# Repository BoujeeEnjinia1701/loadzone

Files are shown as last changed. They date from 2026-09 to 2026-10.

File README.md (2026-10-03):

# LoadZone

     

**Area:** Smart Cities · **TRL:** 3 of 9 (proof of concept on paper) · **Value-engineering target:** USD 120 (estimated cost USD 116) · **Difficulty:** 2 of 5

A curbside loading bay occupancy sensor for streets that are not plowed: it shows delivery drivers which bays are free and gives cities data on curb use.

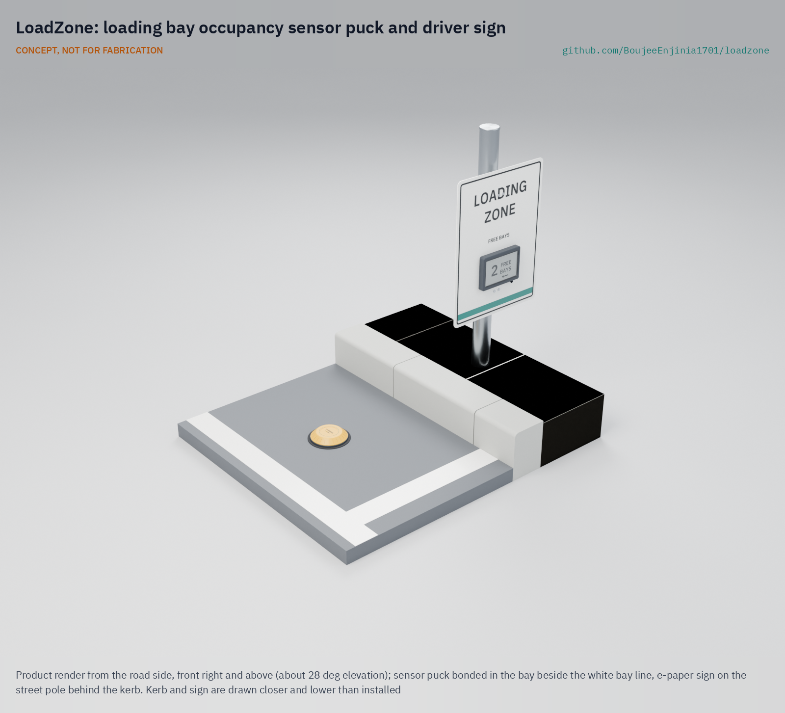
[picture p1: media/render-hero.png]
LoadZone: loading bay occupancy sensor puck and driver sign, product render


[Exploded render](media/render-exploded.png) · [Detail render](media/render-detail.png) · [Interactive 3D model](media/viewer.html) · [Concept blueprint (PDF)](media/concept-blueprint.pdf) · [General arrangement (PDF)](cad/drawings/LDZ-DWG-001.pdf) · [Sizing calculations](docs/04-calcs/01-sizing.md) · [Prototype build plan](docs/05-build-plan.md) · [Design decisions](docs/06-design-decisions.md) · [Review note](docs/REVIEW.md)

## Concept rationale

Knowing bay availability reduces circling and double parking. LoadZone puts a low, battery-powered puck in the middle of each vehicle slot of a loading bay. A magnetometer senses the steel body of a parked vehicle, and a LoRaWAN radio from the lab's FieldNode core reports "free" or "occupied" in about 18 s (39 s at worst). A server turns these reports into live bay state for drivers, and occupancy and dwell times for the city; a solar e-paper sign on an existing pole is an option.

It is open and garage-buildable because curb data should belong to the street, not to a vendor. A magnetometer cannot see faces or number plates, so privacy holds even if the firmware is changed, and anyone can inspect how a "free" or "occupied" call is made. The puck is a cast dome over potted off-the-shelf parts, bonded to the road like a raised pavement marker, and the data can be published in the open Curb Data Specification format so cities can compare it with carrier data.

## Burning platform

Loading bays are full, and often not with deliveries. In a study of downtown Seattle, passenger vehicles were 52 % of all vehicles parked in commercial load zones, and 41 % of commercial vehicles parked in unauthorized locations, rising to 55 to 65 % near retail centers ([Urban Freight Lab, 2019](https://urbanfreightlab.com/publications/the-final-50-feet-of-the-urban-goods-delivery-system-tracking-curb-use-in-seattle/)). The same group reports that commercial load zones often run at 90 % occupancy or more during business hours ([Urban Freight Lab](https://urbanfreightlab.com/final-50-feet/)). A driver who finds the bay taken stops in the traffic lane or the bike lane.

Pressure on the curb keeps rising. Online sales rose from 16 % to 19 % of all retail sales in 2020 ([UNCTAD, 2021](https://unctad.org/news/global-e-commerce-jumps-267-trillion-covid-19-boosts-online-sales)), and in Great Britain van traffic grew 2.3 % to 59.0 billion vehicle miles in the year to September 2024 ([Department for Transport](https://www.gov.uk/government/statistics/provisional-road-traffic-estimates-great-britain-october-2023-to-september-2024)). Cities cannot manage bays they cannot measure, and most loading bays today are measured only by occasional manual surveys.

## Where it could be used

### By industry

| Industry | Use |
| --- | --- |
| Municipal transport and curb management | Occupancy, turnover and dwell time by bay and hour, to size bays and set hours and pricing |
| Parcel, food and freight carriers | Route drivers to a free bay; fewer double-parked stops and tickets |
| Retail streets and business districts | Shared loading bays for shop suppliers, with evidence for more or better-placed bays |
| Parking enforcement | Find overstays in loading bays without patrols or cameras |
| Hospitals, campuses and industrial sites | Manage private loading bays and short-stay drop-off areas |
| Research and education | Open, reproducible curb-use data for transport studies |

### By country or region

| Country or region | Why it matters there |
| --- | --- |
| United States | In downtown Seattle, 41 % of commercial vehicles parked in unauthorized locations ([Urban Freight Lab, 2019](https://urbanfreightlab.com/publications/the-final-50-feet-of-the-urban-goods-delivery-system-tracking-curb-use-in-seattle/)); cities are now comparing curb programs through US DOT SMART grants ([Urban Freight Lab](https://urbanfreightlab.com/research-projects/open-mobility-foundation-smart-grant-curb-collaborative/)) |
| United Kingdom | Van traffic grew 2.3 % to 59.0 billion vehicle miles in the year to September 2024 ([Department for Transport](https://www.gov.uk/government/statistics/provisional-road-traffic-estimates-great-britain-october-2023-to-september-2024)) |
| European Union | Data protection by design is a legal duty ([Regulation (EU) 2016/679, Article 25](https://eur-lex.europa.eu/legal-content/EN/TXT/HTML/?uri=CELEX:32016R0679)), which favors curb sensors that cannot capture personal data at all |
| South Korea | Online sales reached 25.9 % of retail in 2020, the highest share UNCTAD reported ([UNCTAD, 2021](https://unctad.org/news/global-e-commerce-jumps-267-trillion-covid-19-boosts-online-sales)), so dense cities carry heavy parcel traffic |
| India | National guidelines for City Logistics Plans ask cities to optimize loading and unloading lots and to track the daily use of each bay and the number of deliveries it serves ([DPIIT, Guidelines for Preparing City Logistics Plan](https://www.dpiit.gov.in/static/uploads/2025/07/4e218c186c4bdbc202d9f1f62bb9b372.pdf)); a low-cost open sensor can supply that count without cameras |
| Brazil | São Paulo's traffic agency lists 1,749 on-street truck bays reserved for loading and unloading, paid by digital card for one or two hours ([CET São Paulo](https://www.cetsp.com.br/consultas/zona-azul/vagas-especiais/vagas-caminhao.aspx)); sensing could show drivers which are free and show the city how long each stop lasts |

## What sparked the idea

The starting point was San Francisco's SFpark pilot, which set magnetometer "pucks" into metered parking spaces to publish real-time availability. The agency's own sensor data guide records where that approach fell short: the in-ground sensors, 4 in (about 100 mm) across, had batteries intended to last about five years, cut to about three by noise-filtering software, yet some began to fail in late 2012 and early 2013, about a year earlier than expected, and users were advised to aggregate the data by hour and by block to reduce the effect of sensor error ([SFMTA, Parking Sensor Data Guide, 2013](https://www.sfmta.com/sites/default/files/reports-and-documents/2018/08/sfpark_dataguide_parkingsensordata.pdf)). LoadZone takes the same sensing principle to the loading bay, where stops last minutes rather than hours, and answers those lessons in the open: a surface-bonded puck that needs no coring, a cell budget derated 40 % against the five-year target, and firmware and data that a city can inspect rather than rent.

## Problem

Delivery vehicles double-park when loading bays are occupied or unknown, blocking lanes and bike paths. Drivers cannot see whether a bay is free before they reach it, and cities have no routine record of how their loading bays are used. See the [problem statement](docs/01-problem.md).

## Concept

A curbside loading bay occupancy sensor for streets that are not plowed: it shows delivery drivers which bays are free and gives cities data on curb use.

Full design precis: [docs/02-concept.md](docs/02-concept.md)

## Key components

- Surface-bonded bay sensor puck on a two-part road-marker epoxy bed, 150 mm diameter and 31 mm high, cast polyurethane over potted electronics, one per vehicle slot of about 7 m
- 3-axis magnetometer (LIS2MDL class) for vehicle detection
- FieldNode radio core (STM32WL-class LoRaWAN module) with an internal antenna
- Two AA-size lithium thionyl chloride cells, 7.7 years of life at SF9 (calculated, derated 40 %)
- Open server and data feed that maps onto the Curb Data Specification
- Solar signage option: 7.5 in e-paper sign on an existing pole, powered by a host FieldNode, legible by day; needs a private network server such as TwinKit

TRL 3 calculations ([LDZ-CAL-001](docs/04-calcs/01-sizing.md)): state reported in 17.7 s typically and 18.2 s at worst on US915, 7.7 years on one set of cells, and an estimated USD 116 in parts for a two-slot bay against a value-engineering target of USD 120 (USD 4 under it); the sign option (USD 101 plus a USD 139.50 FieldNode) is costed separately. No requirement is now not met. A puck under a parked van reaches a gateway about 340 m away in a street canyon, so each bay needs a gateway within 300 m (R4), and the e-paper sign is a daylight-only aid, unlit at night (R11). Detection of high-clearance trucks (R1), airtime at slow data rates (R5) and the epoxy road bond under braking (R6) are at risk. See the [design precis](docs/02-concept.md), [requirements](docs/03-requirements.md) and design decisions ([LDZ-DDR-001](docs/decisions/0001-trl2-review-decisions.md), [LDZ-DDR-002](docs/decisions/0002-recommendations-accepted.md), [LDZ-DDR-003](docs/decisions/0003-design-for-construction.md)). The parametric model is [cad/src/model.py](cad/src/model.py), with STEP files in `cad/step/`.

The working bill of materials is in [bom/bom.csv](bom/bom.csv).

## Building the prototype

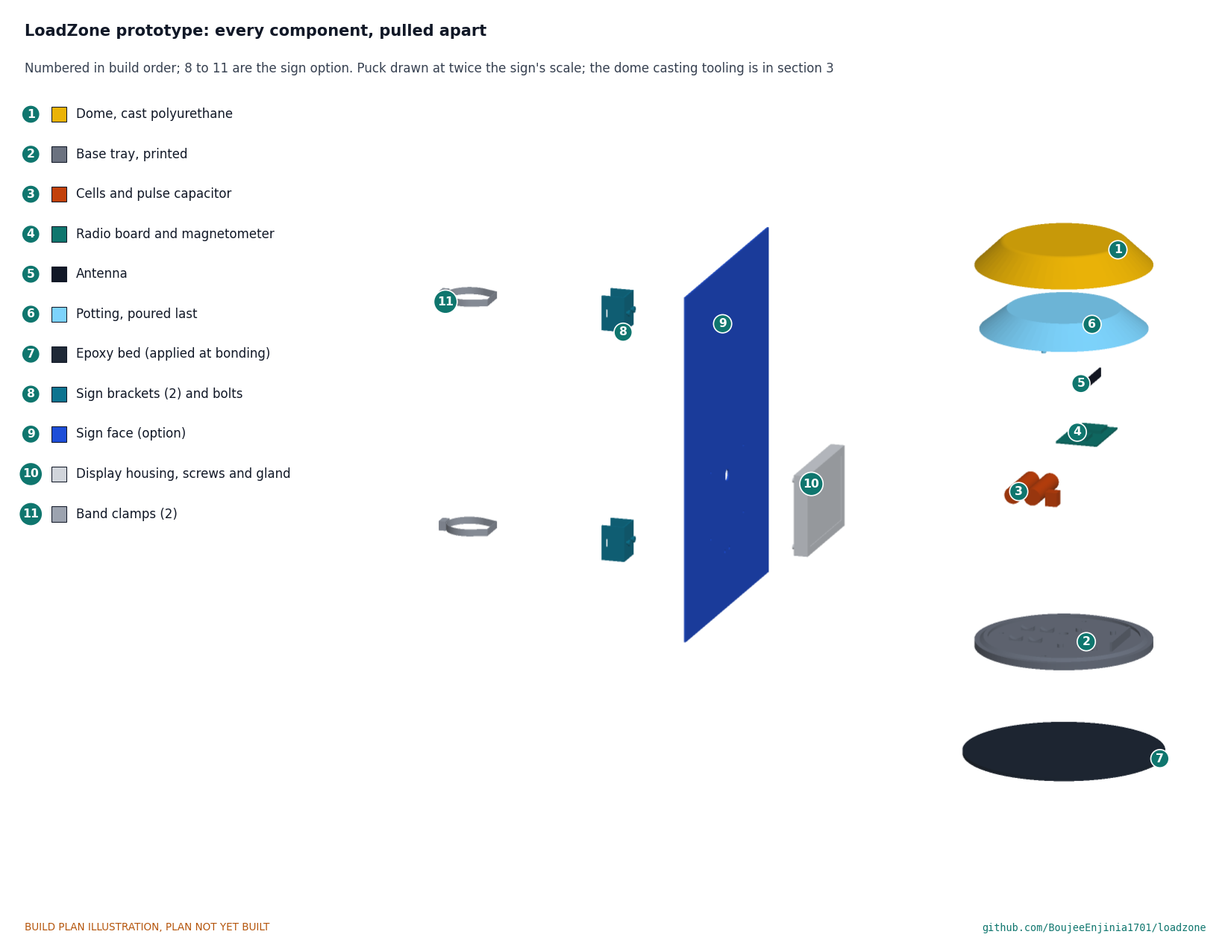
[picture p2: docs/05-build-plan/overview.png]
LoadZone prototype: every component pulled apart and numbered in build order


The [prototype build plan](docs/05-build-plan.md) (LDZ-BLD-001) shows, in pictures, how to make each of the eleven components and put them together in nine steps; nothing has been built yet. Each puck is a polyurethane dome cast in a home-made silicone mould with a printed core, on a printed base tray that holds the cells, radio board and antenna; the puck is then potted solid through a hole in the tray and bonded to a test slab. The sign option is a bought sign face and display housing on two aluminium channel brackets with band clamps. Writing the plan made the design buildable: the base became a tray with a locating ring, fill and vent holes and holders for every part, the dome got a real casting process, and the sign's solid ring clamps became brackets and bands (LDZ-DDR-003, accepted by Amish on 2026-10-02). Every picture is drawn from the model, which checks that each part touches what it should and clears what it should not.

## Safety

> Street furniture and pole mounts must be installed only with the asset owner's permission, by trained crews, with fall protection and traffic management as local rules require.
>
> Pucks are installed in the roadway: work only under a road permit and traffic management. The pucks contain primary lithium thionyl chloride cells: never recharge, short, crush or heat them. Road-marker adhesives and polyurethane casting resins are hazardous; follow their safety data sheets. The surface puck is not for plowed streets, and a sign's legend must follow the city's sign rules and be approved by its traffic engineer before it goes on a street.

## Repository layout

| Folder | Contents |
| --- | --- |
| `docs/` | Problem, concept, requirements, calculations, prototype build plan and design decisions |
| `cad/src/` | build123d Python source, the source of truth for all geometry |
| `cad/step/`, `cad/stl/` | Exported models for FreeCAD, other CAD tools and printing |
| `cad/drawings/` | 2D sketches and dimensioned drawings |
| `bom/` | Bill of materials |
| `electronics/` | KiCad schematics and PCB layouts |
| `firmware/` | Microcontroller code |
| `media/` | Renders, perspectives and photos |
| `build-log/` | Dated prototyping notes |

## Documentation

Controlled documents follow the portfolio [documentation standard](.kit/STANDARDS.md). Each carries a document ID (LDZ-PRC-001 for the precis), a version and a revision history. Branded PDFs are built with `python .kit/render.py` and attached to GitHub Releases when a document is tagged, for example `LDZ-PRC-001/v1.0`.

## Credits

Designed by Amish Chadha. See [CONTRIBUTORS.md](CONTRIBUTORS.md) for roles. To cite this design, use [CITATION.cff](CITATION.cff) (GitHub shows it as "Cite this repository").

AI assistance (Claude) was used to accelerate concept renders, prototype documentation and first-pass sizing calculations. Design direction and all decisions are Amish Chadha's, recorded in this repository's decision records (`docs/decisions/`).

## Licenses

- **Hardware** (CAD, drawings, BOM, electronics): [CERN-OHL-S v2](LICENSE)
- **Software** (firmware, scripts, notebooks): [MIT](LICENSE-SOFTWARE)

A project of the [Design Molecule](https://designmolecule.com) lab.

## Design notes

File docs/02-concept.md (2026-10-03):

---
doc_id: LDZ-PRC-001
title: LoadZone design precis
project: LoadZone
doc_type: Design precis
version: "0.7"
status: Draft
date: '2026-10-02'
author: Amish Chadha
license: CERN-OHL-S-2.0
revisions:
- version: "0.1"
  date: '2026-09-25'
  author: Amish Chadha
  change: Initial scaffold
- version: "0.2"
  date: '2026-09-25'
  author: Amish Chadha
  change: Populate to TRL 2 (architecture, components, first-order numbers, safety, open questions)
- version: "0.3"
  date: '2026-09-25'
  author: Amish Chadha
  change: TRL 3 figures from LDZ-CAL-001; design choices adopted for TRL 3 under LDZ-DDR-001; parametric model and drawing LDZ-DWG-001
- version: "0.4"
  date: '2026-09-25'
  author: Amish Chadha
  change: Recommendations accepted by Amish (DDR-002)
- version: "0.5"
  date: '2026-10-01'
  author: Amish Chadha
  change: "Constructable design (LDZ-DDR-003): base tray and sign brackets; cost against the value-engineering target"
- version: "0.6"
  date: '2026-10-02'
  author: Amish Chadha
  change: 'Decisions of 2026-10-02 carried in (LDZ-DEC-001 items 2 to 7): partner and US915, sealed for life, ASA tray, button heads, legend approval rule, surface puck only and not for plowed streets'
- version: "0.7"
  date: '2026-10-02'
  author: Amish Chadha
  change: 'Radio figures rerun for US915 with the 11-byte payload (LDZ-CAL-001 v0.4): airtime, latency, cell life, link; antenna at 915 MHz; no requirement status changed'
---

# LoadZone design precis

## Summary

LoadZone is a low, battery-powered puck bonded to the road in the middle of each vehicle slot of a loading bay. A 3-axis magnetometer senses the change in the Earth's magnetic field when a vehicle's steel body parks over it, and a LoRaWAN radio from the lab's FieldNode core reports "free" or "occupied" in about 18 s (39 s at worst at SF9). A server turns the reports into bay state, dwell times and an open data feed that maps onto the Curb Data Specification, and, as an option, a solar e-paper sign on an existing pole shows approaching drivers how many slots are free. The TRL 3 calculations (LDZ-CAL-001) give a cell life of 7.7 years at SF9 on two AA-size lithium thionyl chloride cells and a two-slot bay kit estimated at USD 116 in parts against a value-engineering target of USD 120. They also find the weak points: from road level under a parked van a puck reaches a gateway only about 350 m away in a street canyon, so each bay needs a gateway within 300 m (R4 as restated); the road bond is at risk under braking; and the sign is unlit, so it serves drivers by day only (R11 as restated). The design choices below were decided by Amish on 2026-09-25 (LDZ-DDR-001 and LDZ-DDR-002). Writing the prototype build plan (LDZ-BLD-001) made the design constructable without changing what it does (LDZ-DDR-003, open for Amish's review); open items are in the design decisions register (LDZ-DEC-001).

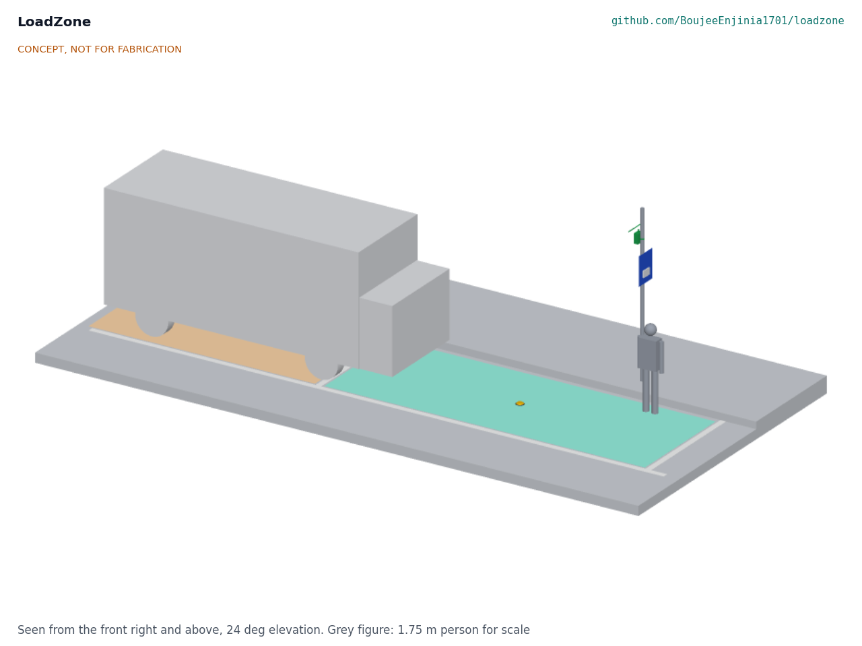
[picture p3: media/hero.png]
LoadZone concept


Figure 1. Concept massing model in a two-slot loading bay: the free slot (teal) with its puck, the occupied slot (orange) under a van, and the optional sign on an existing pole, with a 1.75 m person for scale. CONCEPT, NOT FOR FABRICATION.

## How it works

1. **Sense.** Each puck wakes about once a second and takes a single magnetometer reading. With no vehicle, the reading is the local Earth field plus a fixed offset learned at install. A car or van parked above distorts the field by several microtesla (estimate), mostly in the vertical axis.
2. **Decide.** Firmware compares the field change with an adaptive threshold and requires the new state to hold for about 15 s before accepting it, so traffic passing in the next lane and vehicles pausing briefly do not count. The baseline is re-learned slowly while the slot is free, to follow temperature drift and road works nearby.
3. **Report.** On each confirmed change, and hourly as a heartbeat, the puck sends an 11-byte LoRaWAN uplink: slot state, time since the last change, a confidence value, cell voltage and temperature. The payload is packed to 11 bytes so that it fits the slowest US915 rate (LDZ-DDR-002), and US915 is the default band. No raw magnetic data leave the device by default.
4. **Aggregate.** A LoRaWAN network server (TwinKit, The Things Network or a city network) passes uplinks to a small open service that keeps bay state, computes occupancy and dwell time, and publishes them in a form that maps onto the Curb Data Specification Events and Metrics APIs ([Open Mobility Foundation](https://www.openmobilityfoundation.org/about-cds/)).
5. **Show (option).** A FieldNode on a nearby pole, running as a LoRaWAN class C device, receives a short downlink when the bay state changes and redraws a 7.5 in e-paper panel set into a "Loading zone" sign: the number of free slots and an arrow. The same state can appear in carriers' routing tools and city maps through the data feed.

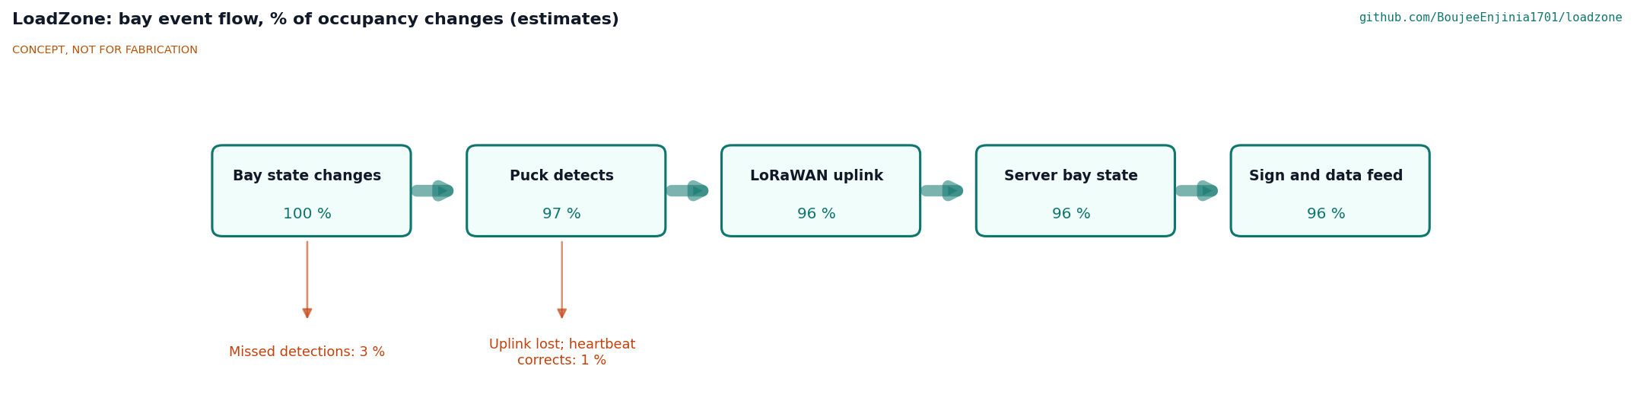
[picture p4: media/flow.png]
Event flow


Figure 2. Bay event flow, in percent of real occupancy changes (estimates, to be measured in a field trial).

## Main components

Table 1. Components (numbers match `bom/bom.csv` and Figure 3)

| No. | Component | Concept choice |
| --- | --- | --- |
| 1 | Puck dome | Rigid cast polyurethane, high-visibility yellow, 150 mm base diameter, 104 mm crown with a 6 mm radius, 31 mm total height, radio-transparent |
| 2 | Magnetometer | 3-axis, 16-bit, LIS2MDL class, on a small breakout ([STMicroelectronics](https://www.st.com/en/mems-and-sensors/lis2mdl.html)) |
| 3 | Controller and radio | STM32WL-class LoRaWAN module on a small carrier, the same core as FieldNode |
| 4 | Antenna | Flexible PCB antenna for 915 MHz (US915 default band), fixed inside the dome wall, above the cells |
| 5 | Cells | Two AA-size Li-SOCl2 bobbin cells (about 2.6 Ah each, typical rating) in parallel through one Schottky diode each, with an 85 °C hybrid pulse capacitor to supply transmit current |
| 6 | Base and potting | Printed 150 x 6 mm base tray with a ring that locates the dome, cradles for the cells, standoffs for the board and a rib for the antenna; the dome cavity is fully potted in semi-rigid polyurethane through a fill hole in the tray, and the potting carries wheel loads through to the base (LDZ-DDR-003) |
| 7 | Road-marker epoxy bed | Two-part road-marker epoxy, as used for raised pavement markers, as a 170 mm bed about 3 mm thick (LDZ-DDR-002; a bitumen pad is no longer used) |
| 8 | Sign face (option) | Aluminium composite panel, 450 x 600 mm, "Loading zone" legend and a window for the display |
| 9 | Display (option) | 7.5 in e-paper panel with driver board, behind a polycarbonate window in a sealed housing |
| 10 | Sign brackets (option) | Two aluminium channel brackets bolted to the back of the sign, each with a stainless band clamp for 60 to 90 mm poles (LDZ-DDR-003) |
| 11 | Host FieldNode (option) | Standard FieldNode (6 W panel, LiFePO4 cell, LoRaWAN class C), mounted above the sign and priced once in the FieldNode repo ($126.00) |

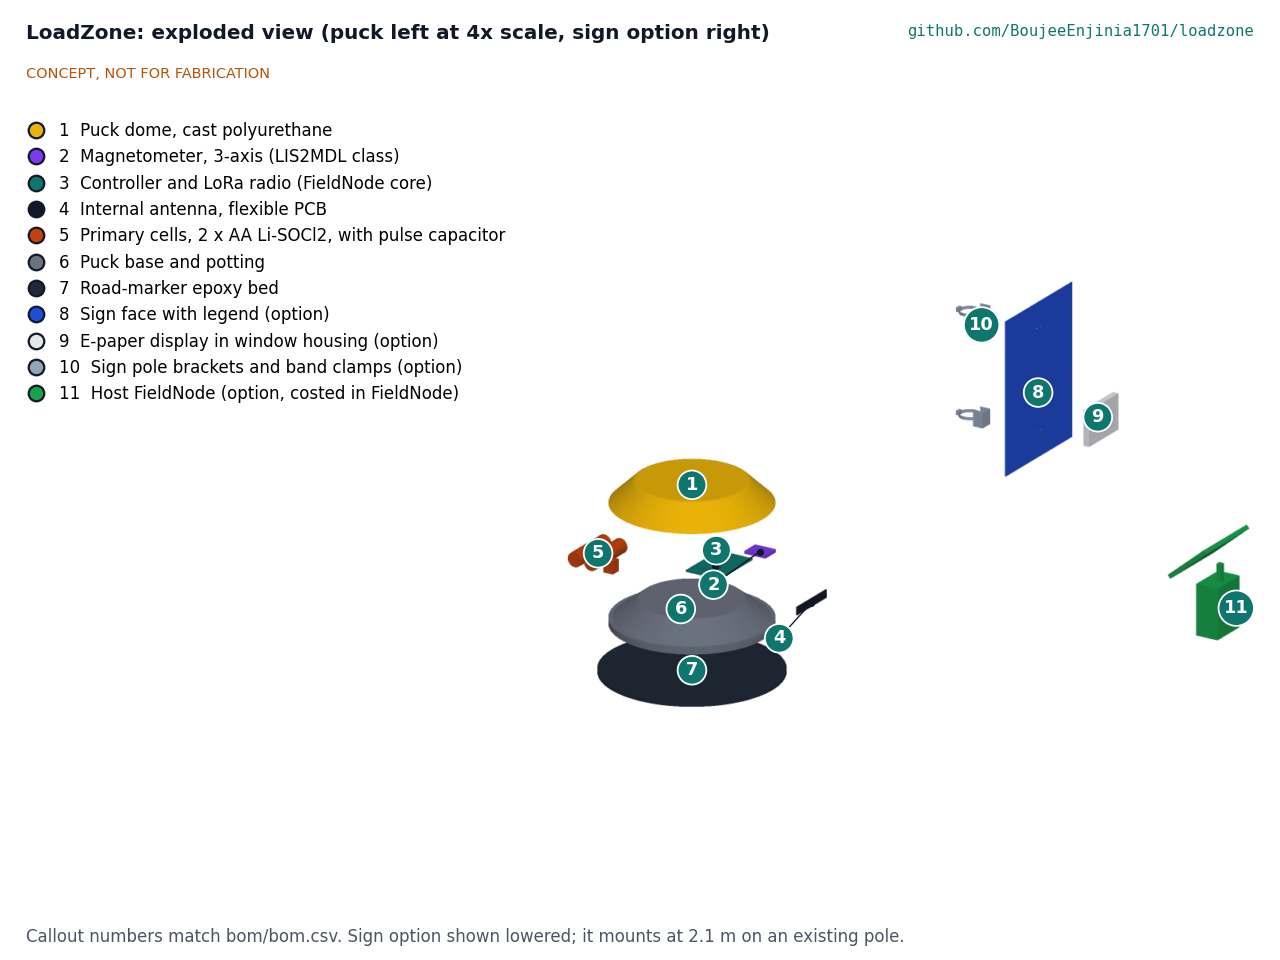
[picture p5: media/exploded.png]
Exploded view


Figure 3. Exploded view; callout numbers match `bom/bom.csv`. The puck is drawn at 4x scale.

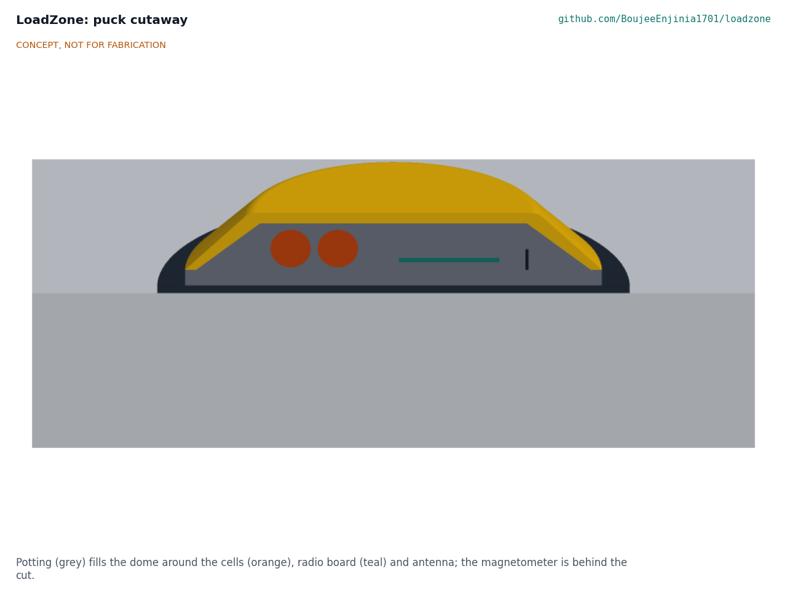
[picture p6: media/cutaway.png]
Cutaway


Figure 4. Puck cutaway: potting (grey) fills the dome around the cells (orange), the radio board (teal) and the antenna at the dome's edge; the magnetometer sits on the board behind the section plane.

The parametric model is `cad/src/model.py` (STEP and STL in `cad/step/` and `cad/stl/`), and the general arrangement of the puck is drawing LDZ-DWG-001 at Rev P2 in `cad/drawings/`.

## First-order numbers

All values are from LDZ-CAL-001 v0.2, which the script `docs/04-calcs/sizing.py` reproduces. They are paper estimates, not measurements.

Table 2. Puck energy budget at SF9

| Quantity | Value | Assumption |
| --- | --- | --- |
| Sleep | 0.144 mAh/day | 6 µA: module in stop mode, magnetometer idle, leakage |
| Sampling | 0.480 mAh/day | One reading a second; 10 ms awake at 2 mA (20 µA average) |
| Uplinks | 0.488 mAh/day | 100 state changes and 24 heartbeats, 14.2 mA·s each at SF9 |
| Total | 1.11 mAh/day, 0.406 Ah/year | Sum of the above |
| Usable cell capacity | 3.12 Ah | 2 x 2.6 Ah, derated 40 % for cold, pulse loads and self-discharge |
| Cell life | 7.7 years | 9.6 years at SF7, 6.2 at SF10; R3 asks for 5 years |

**Airtime.** An 11-byte uplink is on air for 61.7 ms at SF7, 205.8 ms at SF9 and 370.7 ms at SF10, inside the 400 ms US915 dwell limit. At 124 uplinks a day that is 7.7 s at SF7 and 25.5 s at SF9, within The Things Network's 30 s fair-use limit ([TTN](https://www.thethingsnetwork.org/docs/lorawan/duty-cycle/)), but 46.0 s at SF10 (SF11 and SF12 are not offered on US915 uplinks). Pucks must therefore sit within SF9 reach of a gateway (R5 at risk).

**Latency.** A 15 s debounce, up to 1 s of sampling and about 2 s of network path give 17.7 s typically; US915 has no duty-cycle wait, so the worst case is 18.2 s at SF9 and 18.4 s at SF10, well within R2's 60 s.

**Pulse supply.** One SF9 uplink draws 9.3 mC, which a capacitor alone would supply with 0.3 V of droop at 31 mF (56 mF at SF10). Fresh cells sit at about 3.67 V, above the module's 3.6 V limit, so one Schottky diode per cell drops the rail to about 3.42 V and stops one cell charging the other.

**Detection.** The Earth's field is roughly 25 to 65 µT, well within the sensor's ±50 gauss (±5,000 µT) range. A line-dipole model calibrated to an assumed 10 µT under a parked van gives 10.6 µT for a car, 7.7 µT for a high-chassis box truck and 3.85 µT for a truck with little low steel, against a 3 µT threshold, while a van in the next lane gives 0.46 µT. The slot-center position sees vehicles anywhere in the slot and ignores neighbors; high-clearance trucks are the weak case, and R1 stays unverified until field data exist.

**Link.** At 11.5 dBm EIRP the SF9 link budget is 141.0 dB. With 10 dB lost at road level and 10 dB to a van overhead, the 3GPP urban microcell street-canyon model at 915 MHz leaves -6.4 dB at 1 km out of sight and 2.6 dB in line of sight; the range out of sight is about 340 m with a 10 dB fade margin. The original 1 km target is not reachable, so R4 is restated as a gateway within 300 m of each bay (LDZ-DDR-002), which the 342 m range meets on paper.

**Load.** A 49 kN wheel (half of a 10 t axle) on the 92 mm flat crown gives 7.38 MPa, or 9.59 MPa with a 1.3 dynamic factor: a factor of 5.4 on rigid cast polyurethane and 2.0 on the potting beneath. The bond is the weak point: a braking tire could push 34.3 kN sideways, 1.51 MPa on the bed, against about 1.0 MPa for two-part epoxy on asphalt at 20 °C and much less when hot. A vehicle parked inside the bay lines keeps its tires at least 275 mm from the puck axis, so only maneuvering wheels cross it; R6 is restated on that basis with an epoxy bed (LDZ-DDR-002) and stays at risk.

**Sign.** Class C listening costs 15.2 mW and about 200 e-paper redraws a day add 0.015 Wh; the sign draws 0.42 Wh a day (17.7 mW), well within FieldNode's published allowance of 100 mW. Digits 78 mm high read at about 28 m by day on the MUTCD legibility index, better than the 10 m estimated at TRL 2, but the panel is unlit, and a 0.5 W front light would need 6.0 Wh a day, 2.5 times the allowance, so R11 is restated as a daylight-only target (LDZ-DDR-002) and met on paper. The sign takes about 200 downlinks a day, far above The Things Network's 10, so it needs a private network server such as TwinKit (decided, LDZ-DDR-002). Typical 7.5 in e-paper panels operate from about 0 to 50 °C, so refresh on freezing days is a limit to check.

**Mass and size.** Puck 451 g without the pad (75 g), 150 mm diameter, 31 mm high.

**Cost.** Value-engineering target: USD 120, for the two-puck kit only (LDZ-DDR-001, D6). Estimated cost of the constructable design: USD 116 (USD 4 under the target). The sign option adds USD 101 plus a host FieldNode at USD 126, and the one-off dome casting tooling USD 35 (see `bom/bom.csv`).

## Key design choices

Choices 1 to 7 and 9 to 11 are decided by Amish, 2026-09-25: go with recommendation (LDZ-DDR-001, D1 to D8, and LDZ-DDR-002). Choice 8 follows from choice 2. Choices 12 and 13, and the scope note in choice 1, were decided by Amish on 2026-10-02 (LDZ-DEC-001).

1. **Surface-bonded puck rather than an in-ground (cored) sensor.** No road works for a pilot and easy removal. In-ground units are better protected from plows and theft. Decided by Amish, 2026-10-02 (LDZ-DEC-001, item 7): only the surface puck is offered for now, and it is not for plowed streets; the cored, in-ground version is recorded as a later option.
2. **Magnetometer only, rather than magnetometer plus radar.** Lowest cost and power. A small radar looking up through the dome could confirm detections; it stays an open option if R1 is not met in trials.
3. **One puck per vehicle slot of about 7 m**, rather than one per bay. Bays hold one to three vans; slot-level state lets the sign say "1 free" rather than "space somewhere".
4. **Primary Li-SOCl2 cells rather than rechargeable cells with a solar cell on the puck.** A road-level solar cell is shaded by parked vehicles and soiled by tires. Two AA cells give margin over the 5-year target.
5. **LoRaWAN with the FieldNode core.** Shared firmware, tools and gateways across the lab. The sign, as a class C device, receives state by downlink (D7). At about 200 downlinks a day this needs a private network server such as TwinKit; on The Things Network the sign would have to listen to the pucks directly (LoRa point to point), which also keeps it working when the internet link is down. The sign option therefore requires a private network server or a city network that allows the downlinks (LDZ-DDR-002, O5).
6. **E-paper sign as an option, not the core.** It needs no power to hold an image and is readable in sun, but it is small and unlit, so its target is daylight only (R11) and drivers use the data feed at night. Many drivers may use the data through routing tools instead, which co-design should test.
7. **Open data in a Curb Data Specification form**, so a city can compare LoadZone with carrier and payment data.
8. **Privacy by physics.** The puck senses only a magnetic field, so it cannot identify vehicles or people even if its firmware is changed.
9. **Two-part road-marker epoxy bed** rather than a bitumen pad, for bond strength, with R6 restated around maneuvering wheels (LDZ-DDR-002, O3). Pull-off testing is TRL 4 work and on hold.
10. **A gateway within 300 m of each bay** (R4 restated, LDZ-DDR-002, O2), which also keeps pucks at SF9 or faster for R2, R3 and R5.
11. **Supply and potting details:** one Schottky diode per cell, an 85 °C hybrid pulse capacitor, a fully potted cavity and a 6 mm crown radius (LDZ-DDR-002, O6), and an 11-byte payload (O7).
12. **Sealed for life** (LDZ-DEC-001, item 3, decided 2026-10-02): the cells cannot be replaced and the firmware changes only over the air; over-the-air updates are planned for TRL 4. The base tray is printed ASA sanded with 80 grit (item 4), and the sign face shows button heads (item 5).
13. **US915 as the default band** (LDZ-DEC-001, item 2, decided 2026-10-02), since the 11-byte payload already fits it.

## Relationship to other lab projects

- **FieldNode** provides the controller and radio core (the STM32WL-class module) for the puck and the complete host node for the sign option, as its README lists LoadZone among adopting projects. LoadZone uses FieldNode's radio currents and its $126.00 core cost (FND-CAL-001); the sign's 17.7 mW fits FieldNode's published 100 mW allowance.
- **TwinKit** is the default gateway and data platform, and the sign option needs it (or another private network server) for its class C downlinks; for the pucks alone, any LoRaWAN network server works.
- **CurbCount** counts people, bicycles and vehicles passing the curb; LoadZone reports who is stopped at it. Both would feed **CityTwin**.
- **CalRig** could check magnetometer offset and noise before installation.

## Safety

> **Safety:** Installing on a road is dangerous. Work only with the road authority's permit, with a trained crew, under the traffic management that local rules require, and with high-visibility clothing. Never install from a live traffic lane without protection.

> **Safety:** Lithium thionyl chloride cells are primary lithium cells. Do not recharge, short, crush, heat or open them; they can vent toxic and corrosive gas and burn. Connect the two cells in parallel only through one diode each so that one cell can never charge the other, fit a fuse, keep the pulse capacitor within its voltage and temperature rating, and recycle spent cells as hazardous waste.

> **Safety:** Two-part road-marker epoxy is chemically hazardous and some grades are applied hot; uncured resin and hardener irritate skin and can sensitize. Follow the maker's safety data sheet, wear gloves and eye protection, and ventilate. Polyurethane casting resins contain isocyanates; cast only with ventilation and suitable respiratory protection.

> **Safety:** The puck is a raised object in the roadway. Keep it low with rounded edges, place it away from bike lanes and crosswalks, and keep it high-visibility. Check after install that it is fully bonded, since a loose puck can be thrown by a tire.

> **Safety:** The sign option is work at height on a street pole. Use a stable platform with a second person present, keep clear of overhead power lines, and use only poles whose owner permits the added wind load. Deburr the aluminium sign panel's edges. The prototype legend is a placeholder: before a sign is mounted on a street, its legend is drawn to the trial city's sign rules (in the US, the MUTCD) and approved by the city traffic engineer (LDZ-DEC-001, item 6).

## Open questions

- [ ] Detection accuracy with magnetometer only, especially for high-clearance trucks: is a radar or second magnetometer needed to meet R1? Awaiting field data.
- [x] Gateway spacing: a gateway within 300 m of each bay (R4 restated, LDZ-DDR-002).
- [x] Bond: two-part road-marker epoxy, with R6 restated (LDZ-DDR-002).
- [x] Sign: daylight-only target, on a private network server (LDZ-DDR-002).
- [x] First trial partner and band (O1). Decided by Amish, 2026-10-02 (LDZ-DEC-001, item 2): the first candidate type to approach, not yet agreed, is a city curb-management or transportation team that has published or piloted the Curb Data Specification, in a city without routine snow plowing; US915 by default, with the 11-byte payload.
- [x] Snow and plows. Decided by Amish, 2026-10-02 (LDZ-DEC-001, item 7): the surface puck is not for plowed streets; a cored, in-ground version is a later option.

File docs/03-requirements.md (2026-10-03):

---
doc_id: LDZ-REQ-001
title: LoadZone requirements
project: LoadZone
doc_type: Requirements
version: "0.7"
status: Draft
date: '2026-10-02'
author: Amish Chadha
license: CERN-OHL-S-2.0
revisions:
- version: "0.1"
  date: '2026-09-25'
  author: Amish Chadha
  change: Initial scaffold
- version: "0.2"
  date: '2026-09-25'
  author: Amish Chadha
  change: First measurable requirements for TRL 2, with status against the concept
- version: "0.3"
  date: '2026-09-25'
  author: Amish Chadha
  change: TRL 3 status from LDZ-CAL-001; R6 load basis set; R13 redefined to the two-puck kit (LDZ-DDR-001 D6)
- version: "0.4"
  date: '2026-09-25'
  author: Amish Chadha
  change: Recommendations accepted by Amish (DDR-002)
- version: "0.5"
  date: '2026-10-01'
  author: Amish Chadha
  change: Constructable design (LDZ-DDR-003); R13 reported against the value-engineering target
- version: "0.6"
  date: '2026-10-02'
  author: Amish Chadha
  change: 'Band assumption: US915 by default (LDZ-DEC-001, item 2, decided 2026-10-02); no status changed'
- version: "0.7"
  date: '2026-10-02'
  author: Amish Chadha
  change: 'Calculation figures brought into line with LDZ-CAL-001 v0.4 (US915); no requirement status changed'
---

# LoadZone requirements

These are the requirements for the concept, checked by calculation at TRL 3 in LDZ-CAL-001 v0.4 on the constructable design of LDZ-DDR-003 and the US915 default band (LDZ-DEC-001, item 2); neither changes a requirement status. On 2026-09-25 Amish accepted the recommendations (LDZ-DDR-002), so this version restates three targets: R4 is now a gateway within 300 m of the bay rather than 1 km; R6 is restated with the finding that the wheels of a vehicle parked inside the bay lines straddle the puck, and the bond is two-part road-marker epoxy; and R11 is a daylight-only target. R13 covers the two-puck bay kit only, with the sign option costed separately (LDZ-DDR-001 D6, now decided); its figure is a value-engineering target, not a spending limit (Amish, 2026-10-01). R12 uses FieldNode's published 100 mW allowance.

Table 1. Requirements

| ID | Requirement | Target | Status at TRL 3 (LDZ-CAL-001) | Verification |
| --- | --- | --- | --- | --- |
| R1 | Detect the state of each vehicle slot | 97 % or more of slot states correct over a day, for cars, vans and box trucks, with traffic passing in the next lane | **At risk**, not verifiable at TRL 3: a line-dipole model puts a van at 10.0 µT, a weak-steel box truck at 3.85 µT and next-lane traffic at 0.46 µT against a 3 µT threshold, on an assumed calibration | Field trial against a manual count or time-lapse survey (TRL 5) |
| R2 | Report changes quickly | Slot state at the server within 60 s of a vehicle arriving or leaving | Met on paper: 17.7 s typical, 18.2 s worst at SF9, 18.4 s at SF10 (US915 has no duty-cycle wait) | Timing calculation (TRL 3) |
| R3 | Long battery life | 5 years or more at 100 state changes a day plus hourly heartbeats | Met on paper: 7.7 years at SF9 on two AA-size Li-SOCl2 cells derated 40 %; 6.2 years at SF10 | Power budget calculation (TRL 3) |
| R4 | Reach a gateway from road level | Uplinks received by a gateway within 300 m of the bay in a street canyon, with a van parked over the puck (restated from 1 km, LDZ-DDR-002) | Met on paper: 342 m out of sight at SF9 with a 10 dB fade margin, 1.14 times the distance | Link budget (TRL 3), then field survey |
| R5 | Stay within network fair use | 30 s or less of uplink airtime per puck per day ([TTN fair use](https://www.thethingsnetwork.org/docs/lorawan/duty-cycle/)) | **At risk**: 25.5 s a day at SF9, but 46.0 s at SF10 (SF11 and SF12 are not offered on US915 uplinks) | Airtime calculation (TRL 3) |
| R6 | Survive traffic | Withstand a maneuvering wheel crossing the puck at 49 kN (half of a 10 t single axle), 64 kN with a 1.3 dynamic factor, and repeated drive-overs by loaded trucks, without cracking or debonding, on a two-part road-marker epoxy bed. The puck sits at the slot center so that the wheels of a vehicle parked inside the bay lines straddle it (restated, LDZ-DDR-002) | **At risk**: crushing met on paper (factor 5.4 on the cast dome, 2.0 on the potting); parked wheels clear the puck by at least 275 mm; bond shear under braking 1.51 MPa against about 1.0 MPa assumed for epoxy on asphalt | Load calculation (TRL 3), then load and pull-off test (TRL 4, on hold) |
| R7 | Safe, low profile | Height 35 mm or less above the road, rounded edges, high-visibility color | Met on paper: 31 mm high, 150 mm diameter, 6 mm crown radius, yellow dome | Parametric model and drawing LDZ-DWG-001 |
| R8 | Weather and temperature | Sealed to IP68; operate from -25 to +70 °C road surface temperature; resist salt, oil and fuel | Met by design: parts rated -40 to +85 °C with an 85 °C pulse capacitor; fully potted. Sealing not verifiable at TRL 3 | Datasheet review (TRL 3), then immersion test |
| R9 | Privacy by design | Only slot state, timestamps and device health leave the device; no images, audio or vehicle identifiers | Met by design: a magnetometer cannot read plates or faces | Design review |
| R10 | Open data | Bay state available through an open API that maps onto the Curb Data Specification Events and Metrics APIs ([Open Mobility Foundation](https://www.openmobilityfoundation.org/about-cds/)) | Met by design: events map onto `park_start`, `park_end`, `scheduled_report`, `comms_lost` and `comms_restored` | Design review (TRL 3) |
| R11 | Sign legible to drivers (option) | Free-slot count legible at 25 m by day (daylight only, restated, LDZ-DDR-002); at night drivers use the data feed | Met on paper: about 28 m by day at full contrast with 78 mm digits | Legibility calculation (TRL 3) |
| R12 | Sign power (option) | Sign runs within the host FieldNode's sensor energy allowance | Met on paper: 0.42 Wh a day (17.7 mW) against FieldNode's published 100 mW; needs a private network for its 200 downlinks a day (LDZ-DDR-002, O5) | Power budget (TRL 3) |
| R13 | Low cost | Two-puck bay kit in parts at quantity 1 against a value-engineering target of USD 120; the sign option and its host FieldNode are costed separately and excluded | Met on paper: estimated USD 116.00, USD 4.00 under the target. Sign option USD 101.00 plus a FieldNode at USD 126.00 | Priced BOM |
| R14 | Quick install without road works | One puck bonded in 15 min or less by a two-person crew; removable without damaging the road | Not verifiable at TRL 3 | Install trial (TRL 4 or later) |
| R15 | Tamper and theft resistant | No external screws; removal needs a heat gun or scraper; device reports removal | Met by design: bonded, no fasteners; removal flagged by a sudden field and orientation change | Design review (TRL 3) |

## Requirements at risk at TRL 3

No requirement is now not met. Before LDZ-DDR-002, R4 (1 km) and R11 (night) were not met; both are restated and met on paper.

- **R1 (detection)** is at risk for high-clearance trucks and rests on an assumed signal; only field data can settle it.
- **R5 (airtime)** is not met at SF10, the slowest US915 rate; R2 and R3 still hold there, but pucks must be placed within SF9 reach of a gateway, which the 300 m gateway distance in R4 supports.
- **R6 (traffic)** is at risk on debonding under braking, even with the epoxy bed; a pull-off and shear test on asphalt would settle it, but that is TRL 4 work and on hold.

## Assumptions

- A vehicle slot is about 7 m long and the puck sits near its center, 1.3 m from the curb face (estimates; bay layouts vary by city).
- Loading bay turnover of up to 50 vehicles a slot a day, or 100 state changes, based on most delivery stops lasting 30 minutes or less ([Urban Freight Lab, 2019](https://urbanfreightlab.com/publications/the-final-50-feet-of-the-urban-goods-delivery-system-tracking-curb-use-in-seattle/)).
- Each 11-byte LoRaWAN uplink costs about 14.2 mA·s at SF9 with FieldNode's radio currents (LDZ-CAL-001). US915 is the default band (LDZ-DEC-001, item 2, decided 2026-10-02), so the payload is packed to 11 bytes (LDZ-DDR-002) and LDZ-CAL-001 v0.4 uses the US915 rules (no duty cycle, 400 ms dwell limit, SF7 to SF10 on uplinks).
- The wheel load is half of a 10 t single axle (49 kN); a vehicle parked inside the bay lines straddles the puck, so wheel loads come from maneuvering (LDZ-CAL-001, section 7).

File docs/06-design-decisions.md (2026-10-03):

---
doc_id: LDZ-DEC-001
title: LoadZone design decisions register
project: LoadZone
doc_type: Design decisions register
version: "0.3"
status: Draft
date: '2026-10-02'
author: Amish Chadha
license: CERN-OHL-S-2.0
revisions:
  - version: "0.1"
    date: '2026-10-01'
    author: Amish Chadha
    change: Register opened with the open decisions from the review note, the decision records and the build plan work; budget treated as a value-engineering target
  - version: "0.2"
    date: '2026-10-02'
    author: Amish Chadha
    change: Amish approved the recommendations of open items 1 to 10 on 2026-10-02; all moved to decisions made; tray bond line to confirm updated
  - version: "0.3"
    date: '2026-10-02'
    author: Amish Chadha
    change: 'Value engineering: host FieldNode priced at USD 139.50 (FND-CAL-001)'
---

# LoadZone design decisions register

Every design decision still to be made, and every decision made, in one place. Each decision is argued in full in its decision record under `docs/decisions/`; this register is the index Amish works from. The build plan (`docs/05-build-plan.md`) describes the design as it stands and does not list open decisions.

## Open decisions

None. All open decisions were decided on 2026-10-02.

## To confirm when parts are bought

| # | What to confirm | Why it matters | Source |
| --- | --- | --- | --- |
| 1 | The display enclosure's real size, its clear lid and its wall thickness | The 4 screw holes, the gland hole and the sign face holes are drawn for about 200 x 140 x 24 mm; move them to suit | LDZ-DDR-003, P8 |
| 2 | The e-paper driver board takes commands from the host FieldNode over a cable about 1 m long, and the pin assignment of the FieldNode sensor port | Sets the cable and connector between the sign and the FieldNode; the FieldNode port pinout is still open in FieldNode | LDZ-DDR-003, P8; FND-DEC-001 |
| 3 | The band clamp range covers the band path for 60 to 90 mm poles (about 250 to 330 mm) | The band runs through the bracket as well as round the pole | LDZ-DDR-003, P7 |
| 4 | The silicone cures against the primer used on the master and core | Some primers stop platinum silicone curing | Build plan, section 3.2 |
| 5 | The potting's peak exotherm for about 175 cm³ against the cells' temperature rating | The potting is poured over live cells | Build plan, safety stop S4 |
| 6 | The magnetic offset of the cells' steel cans at the magnetometer, about 30 mm away | A fixed offset is learned at install; it must not use up the sensor range | LDZ-CAL-001, section 6 |
| 7 | The road-marker epoxy's bond to ASA sanded with 80 grit (decided 2026-10-02; the tray is cast in polyurethane if the TRL 4 pull-off test fails on the tray side) | A second bond line beside the asphalt bond already at risk under R6 | LDZ-DDR-003, A2 |

## Value engineering

Value-engineering target: USD 120 (a hypothetical control target, not a limit). Estimated cost of the constructable design: USD 116 for the two-puck kit (USD 4 under the target). The sign option (USD 101) and its host FieldNode (USD 139.50, priced in the FieldNode repo) are costed separately, and the one-off dome casting tooling (USD 35) is not part of the per-kit cost. Main cost drivers and savings worth trying:

- The largest lines, for two pucks, are the radio module and board (USD 28), the cell sets with diodes and pulse capacitor (USD 28), the magnetometer breakouts (USD 16), the base trays and potting (USD 12) and the domes (USD 10).
- Making the design constructable added USD 2 to the kit (sealant, screws and mould release in line 12) and USD 4 to the sign option (the channel brackets); the tooling is new.
- Savings worth trying: the magnetometer chip and the radio module on one small carrier board instead of two breakouts (a TRL 4 board design); cells bought in tens; one set of casting tooling shared by every puck made, so its cost falls per puck as more are cast.

## Decisions made

| Date | Decision | Decided by | Record |
| --- | --- | --- | --- |
| 2026-09-25 | TRL 2 review items D1 to D8: surface-bonded puck, magnetometer only, one puck per 7 m slot, two AA-size Li-SOCl2 cells, cast polyurethane dome over fully potted electronics, sign outside the kit cost, class C downlink to the sign, a feed that maps onto the Curb Data Specification | Amish: "i accept all your recommendations, go with them across all repos." | LDZ-DDR-001, LDZ-DDR-002 |
| 2026-09-25 | TRL 3 items O2 to O7: gateway within 300 m (R4), road-marker epoxy bed and R6 restated, daylight-only sign (R11), private network server for the sign, diode per cell, 85 °C pulse capacitor, full potting and 6 mm crown radius, 11-byte payload if US915 | Amish, same instruction | LDZ-DDR-002 |
| 2026-09-30 | Make the design physically buildable as the build plan is drawn | Amish: "If you are realising that the design cannot be built as per concept - fix the design assumptions to match and be physically feasible as you draw the illustrations." The resulting changes were accepted on 2026-10-02 (below) | LDZ-DDR-003 |
| 2026-10-01 | `budget_usd` is a value-engineering target, not a limit | Amish: "the budgets are a hypothethical control target to ensure we are thinking along a value engineering lens. its ok to ensure wording reflects that the hypothesis budget was x - the real cost being accrued is y" | This register, Value engineering |
| 2026-10-02 | Open item 1: design for construction accepted: the changes P1 to P8 and their knock-on changes, as made | Amish: "i approve your recommendations for all 555 open decisions." | LDZ-DDR-003, Tables 1 and 2 |
| 2026-10-02 | Open item 2: first trial partner, the first candidate type to approach (not yet agreed), is a city curb-management or transportation team that has published or piloted the Curb Data Specification, in a city without routine snow plowing; US915 is the default band, since the 11-byte payload already fits it | Amish: "i approve your recommendations for all 555 open decisions." | LDZ-DDR-001, O1; LDZ-DDR-002 |
| 2026-10-02 | Open item 3: the puck is sealed for life (cells not replaceable, firmware changed only over the air); over-the-air updates are planned for TRL 4 | Amish: "i approve your recommendations for all 555 open decisions." | LDZ-DDR-003, A1 |
| 2026-10-02 | Open item 4: base tray in printed ASA, sanded with 80 grit, for the first prototype; cast in polyurethane if the TRL 4 pull-off test fails on the tray side | Amish: "i approve your recommendations for all 555 open decisions." | LDZ-DDR-003, A2 |
| 2026-10-02 | Open item 5: button heads on the sign face for the prototype | Amish: "i approve your recommendations for all 555 open decisions." | LDZ-DDR-003, A3 |
| 2026-10-02 | Open item 6: the placeholder legend is kept for now; once the city is chosen the legend is drawn to its sign rules (in the US, the federal sign manual, MUTCD), and the city traffic engineer's approval is obtained before it is mounted on a street | Amish: "i approve your recommendations for all 555 open decisions." | Review note 2026-09-26, item 4 |
| 2026-10-02 | Open item 7: the surface puck only is offered for now and is stated not to be for plowed streets; the cored, in-ground version is recorded as a later option | Amish: "i approve your recommendations for all 555 open decisions." | LDZ-PRC-001, open questions; LDZ-DDR-001, D1 |
| 2026-10-02 | Open item 8: the dome surface detail stays appearance only until the mould is designed for production | Amish: "i approve your recommendations for all 555 open decisions." | Review note 2026-09-26, item 2 |
| 2026-10-02 | Open item 9: the clear amber potting is a render convention unless a clear grade costs no more | Amish: "i approve your recommendations for all 555 open decisions." | Review note 2026-09-26, item 3 |
| 2026-10-02 | Open item 10: the render layout is accepted, and the host FieldNode is mentioned in the caption | Amish: "i approve your recommendations for all 555 open decisions." | Review note 2026-09-26, items 1 and 5 |

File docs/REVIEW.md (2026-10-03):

# Review note: LoadZone

## Session 2026-09-25: /populate to a strong TRL 2

### What was done

- `docs/01-problem.md` (LDZ-PRB-001 v0.2): problem in numbers, users and context, prior work with sources, constraints, out of scope; co-design checklist kept and made specific.
- `docs/03-requirements.md` (LDZ-REQ-001 v0.2): 15 measurable requirements (R1 to R15) with targets, status against the concept and planned verification.
- `docs/02-concept.md` (LDZ-PRC-001 v0.2): how it works, components, first-order numbers, design choices, relationship to other lab projects, safety, open questions.
- `cad/src/concept_media.py`: massing model of the bay sensor puck (BOM 1 to 7) and the sign option on an existing pole (BOM 8 to 11), in a two-slot street bay with a parked van and a 1.75 m person.
- `media/`: `hero.png`, `concept-blueprint.png`, `.pdf` and `.svg`, `model.glb` with `viewer.html`, `exploded.png` (puck drawn at 4x scale, callouts match the BOM), `cutaway.png` (puck section) and `flow.png` (bay event flow, estimates).
- `bom/bom.csv` and `bom/bom-notes.md`: 12 lines with indicative prices, numbered to match the exploded view.
- `README.md`: hero, links line, and the required sections expanded with cited figures.
- `docs/pdf/`: branded PDFs of the three controlled documents.
- `project.yaml`: unchanged. The pitch and problem still match the numbers found.

### Key results (estimates, to be checked at TRL 3)

| Quantity | Estimate | Requirement |
| --- | --- | --- |
| Puck size | 150 mm diameter, 31 mm high | R7 met |
| Report latency | about 20 s | R2 met |
| Cell life | about 7 years on 2 x AA Li-SOCl2 | R3 met |
| Airtime | about 9 s/day at SF7, about 31 s/day at SF9 | R5 partly met |
| Sign power | about 0.4 Wh/day | R12 met |
| Sign legibility | about 10 m by day, unlit at night | R11 not met |
| Two-slot kit cost | about $110 | R13 met |
| With sign option | about $207 plus a FieldNode (about $126) | R13 not met |

**Requirements not met:** R6 (traffic loads) with a printed housing, R11 (sign legible at 25 m and at night), and R13 if the sign option is included. R5 is met only at SF8 or faster unless heartbeats drop to every 2 h. R1 (detection accuracy), R4 (link from under a vehicle), R8, R14 and R15 are unverified.

### Proposed, awaiting Amish

1. **Installation:** surface-bonded puck for pilots (recommended), or a cored in-ground puck (better protected, needs road works).
2. **Sensing:** magnetometer only (recommended for TRL 3), or magnetometer plus a small upward radar if field data show R1 is missed.
3. **Granularity:** one puck per vehicle slot of about 7 m (recommended), or one per bay (cheaper, cannot say how many slots are free).
4. **Power:** two AA-size Li-SOCl2 primary cells (recommended), or one C-size cell (more margin, taller puck), or rechargeable with a road-level solar cell (not recommended; shaded by vehicles).
5. **Housing:** cast polyurethane dome over potted electronics (recommended), a commercial raised pavement marker shell, or a cast aluminium base.
6. **Sign option and budget:** keep the sign as a separate option outside the $120 budget (recommended); or raise `budget_usd` to about $210 to include sign parts (FieldNode excluded) or about $340 including a FieldNode; or drop the sign in favor of a data feed only. The budget in `project.yaml` is unchanged.
7. **Sign data path:** LoRaWAN class C downlink (recommended, simplest with TwinKit), or the sign listening to pucks directly by LoRa point to point (works offline).
8. **Data format:** publish a feed that maps onto the Curb Data Specification (recommended), or implement the specification directly.
9. **First trial partner:** a city curb team, a business district or a carrier; and the LoRaWAN band.

### Safety concerns

- Road installation: permit, trained crew and traffic management are mandatory; the precis and README say so.
- Primary lithium thionyl chloride cells: no recharging, fusing, and disposal as hazardous waste.
- Adhesives and polyurethane resins (isocyanates) need ventilation and protective equipment.
- A loose puck can be thrown by a tire: bond checks after install, and placement away from bike lanes and crosswalks.
- Sign option is work at height near possible overhead lines.

### Recommended next step

Review this note and the media. If approved, run `/advance-trl3` to check by calculation the power budget, airtime, link budget from under a vehicle, the housing load case and sign legibility, then produce the parametric puck model with STEP export and a drawing sheet. A short field log of magnetometer readings under parked vans would reduce the R1 risk most, but that is TRL 4 work and has not been started.

Suggestion (not in the repo): CurbCount and LoadZone could share one server and data feed through CityTwin.

## Session 2026-09-25: TRL 3

On 2026-09-25 Amish asked for this batch of repos to be taken through the usual process with the instruction "you know the drill, nothing gets past TRL 3". He has not reviewed this repo's TRL 2 items one by one, so every item that carried a recommendation is adopted as recommended for TRL 3 under Amish's 2026-09-25 instruction, open for his review. This session ran `/advance-trl3` on that basis and stopped at TRL 3.

### What was done

- `docs/decisions/0001-trl2-review-decisions.md` (LDZ-DDR-001 v0.1, status proposed): eight items adopted as recommended for TRL 3, open for Amish's review (D1 to D8); O1 left open; six new items raised (O2 to O7).
- `docs/04-calcs/01-sizing.md` (LDZ-CAL-001 v0.1) and `docs/04-calcs/sizing.py`: airtime, energy and cell life, pulse supply, latency, link from road level, detection, loads and bond, size and mass, sign power, legibility and downlinks, and cost, with a status for every requirement. The script imports the model, reads the BOM and `project.yaml`, prints every quoted number with a tag and writes `docs/04-calcs/results.csv`.
- `cad/src/model.py`: parametric build123d puck (pad, base, filleted dome, potting, two cells, pulse capacitor, carrier with module, magnetometer, antenna) and sign option (face, display housing, band clamps). Exports `cad/step/` and `cad/stl/` for `loadzone-puck`, `loadzone-dome` and `loadzone-sign-option`.
- `cad/src/sheets.py` and `cad/drawings/LDZ-DWG-001.svg`, `.pdf`, `.png`: general arrangement of the puck at Rev P1, 1:2, marked "CONCEPT, NOT FOR FABRICATION" and "PRELIMINARY, NOT FOR FABRICATION". LDZ-DWG-001 was free because the concept blueprint is LDZ-DWG-010.
- `bom/bom.csv` (12 lines, all priced with a supplier or supplier type; item 11 now carries FieldNode's $126.00 for reference) and `bom/bom-notes.md`.
- `cad/src/concept_media.py` now builds the puck and sign from the model; all of `media/` was re-rendered and every image checked. The cutaway caption was corrected because the potting now hides the magnetometer. No `media/_views*` folders remain.
- LDZ-PRB-001, LDZ-PRC-001 and LDZ-REQ-001 revised to v0.3; `README.md` (TRL badge and line, links, key figures, components) and `project.yaml` (`trl: 3`, `trl_target: 3`, evidence list) updated. PDFs rebuilt in `docs/pdf/`.

### Requirement status (LDZ-CAL-001, Table 2)

2 not met, 3 at risk, 1 not verifiable at TRL 3, 5 met on paper, 4 met by design.

| ID | Status | Key number |
| --- | --- | --- |
| R4 Link from road level | **Not met** | -6.0 dB at 1 km out of sight at SF9 with a van over; about 350 m with a 10 dB fade margin |
| R11 Sign legibility | **Not met** (night) | About 28 m by day at full contrast (TRL 2 said 10 m); unlit at night; a 0.5 W light needs 2.5 times FieldNode's 100 mW allowance |
| R1 Detection | At risk | Line-dipole model: van 10.0 µT, weak-steel truck 3.85 µT, next lane 0.46 µT against 3 µT; calibration assumed |
| R5 Airtime | At risk | 25.5 s/day at SF9 (TRL 2 said 31 s); 51.0 s at SF10 |
| R6 Traffic | At risk | Crown 7.4 MPa, factor 5.4 on PU, 2.0 on potting; bond shear 1.51 MPa against about 1.0 MPa assumed |
| R14 Install time | Not verifiable at TRL 3 | Needs an install trial |
| R2, R3, R7, R12, R13 | Met on paper | 38.6 s worst latency at SF9; 7.7 years; 31 mm high; 0.42 Wh/day sign; $114.00 |
| R8, R9, R10, R15 | Met by design | CDS event types checked against the specification |

Other corrections to TRL 2 figures: puck mass 451 g (was 0.35 kg) because the cavity is fully potted; kit cost $114.00 (was about $110) with the diodes and 85 °C capacitor.

### Decisions recorded (LDZ-DDR-001)

Adopted as recommended for TRL 3 under Amish's 2026-09-25 instruction, open for his review: D1 surface-bonded puck; D2 magnetometer only; D3 one puck per 7 m slot; D4 two AA-size Li-SOCl2 cells; D5 cast polyurethane dome over fully potted electronics; D6 sign outside the $120 budget, which now covers the two-puck kit only (R13 redefined; `budget_usd` unchanged); D7 LoRaWAN class C downlink to the sign; D8 a feed that maps onto the Curb Data Specification. No reworded pitch or problem was recommended, so `project.yaml` and `README.md` keep the existing wording.

### Still awaiting Amish

1. **O1, first trial partner and LoRaWAN band.** No preference stated. Proposed, awaiting Amish.
2. **O2, R4.** Recommendation: restate R4 as a gateway within 300 m of the bay. Not applied.
3. **O3, R6 bond.** Recommendation: two-part road-marker epoxy, and restate R6 with the finding that parked wheels straddle the puck. Not applied.
4. **O4, R11.** Recommendation: a daylight-only legibility target. Not applied.
5. **O5, sign network.** About 200 downlinks a day against The Things Network's 10: the sign needs TwinKit or another private network server.
6. **O6, engineering proposals:** a Schottky diode per cell, an 85 °C hybrid pulse capacitor, the fully potted cavity and a 6 mm crown radius. In the model and BOM, awaiting confirmation.
7. **O7, payload.** Pack the payload into 11 bytes if the band is US915.

### Cross-repo consistency

- FieldNode (TRL 3): LoadZone uses its radio currents, SF9 sensitivity and $126.00 core cost, and its adopted choices (LoRaWAN, STM32WL-class module, TwinKit first). The sign's 17.7 mW fits both the published 115 mW allowance and the 100 mW FieldNode proposes. No conflict.
- TwinKit (TRL 3): its airtime figures use a 20-byte reading; LoadZone's 12-byte uplink is shorter. TwinKit's review does not mention class C downlinks; the sign's 200 downlinks a day use 0.38 % of the RX2 sub-band allowance, but TwinKit's network stack must support class C. Noted here; TwinKit not edited.
- CalRig: could check magnetometer offset and noise before installation; no interface assumed. CellGuard, MotionCore and ThermaCart are not used.

### Safety concerns

- Road installation: permit, trained crew and traffic management; a loose puck can be thrown by a tire, and the calculated bond margin under braking is below 1 on the upper bound, so bond checks after install matter.
- Primary Li-SOCl2 cells in a hot road: parallel cells only through a diode each, fused, never recharged; the pulse capacitor must be rated for 85 °C; spent cells are hazardous waste.
- Polyurethane resins (isocyanates) and road adhesives: ventilation and protective equipment.
- Sign option: work at height near possible overhead lines; pole owner's consent for wind load.

### Gaps and notes

- Citations: none were flagged as unchecked at TRL 2. The Things Network fair-use figures (30 s uplink, 10 downlinks a day) and the Curb Data Specification event types were checked by WebFetch on 2026-09-25. The MUTCD legibility index (section 2A.13) and 3GPP TR 38.901 are cited by section, not fetched.
- Assumptions only tests can settle: the 10 µT vehicle signal, the 10 dB road-level and 10 to 20 dB vehicle losses, adhesive-to-asphalt strength, and material strengths.
- The UMi path-loss model is used below its 1.5 m height floor; the road-level loss term covers this.
- The kit's cutaway cuts at the mean Y of the parts; the puck (at Y = -1.3 m) is passed alone with a slab of road, as at TRL 2, and the section shows the cells, board and antenna. The magnetometer falls behind the cut and appears only in the exploded view. The concept blueprint's orthographic views are small because the street context sets the scale; the GA sheet shows the puck at 1:2.
- Existing material beyond TRL 3: `build-log/README.md` (scaffold) and empty `electronics/` and `firmware/` placeholders are present, untouched and not extended. No test, build or firmware material was created.

### Recommended next step

TRL 4 is on hold by Amish's instruction; this repo stops at TRL 3. Amish's review is needed on D1 to D8 and O1 to O7. For the record only, TRL 4 would need: a bench build of one puck; a lab test report (TST, `environment: lab`) covering magnetometer readings under parked vehicles, sleep current and charge per uplink, a crush test of the cast and potted puck, a pull-off and shear test of the bond on asphalt at 20 and 50 °C, and immersion sealing; and build log entries. None of this has been started.

## Session 2026-09-25: recommendations accepted

On 2026-09-25 Amish wrote: "i accept all your recommendations, go with them across all repos." Every item with a recommendation is now **Decided by Amish, 2026-09-25: go with recommendation**, recorded in `docs/decisions/0002-recommendations-accepted.md` (LDZ-DDR-002 v0.1). Nothing past TRL 3 was done.

### Decisions applied and what changed

| Item | Decision | Before | After |
| --- | --- | --- | --- |
| D1 to D8 | As recommended in LDZ-DDR-001 | "Adopted as recommended for TRL 3, open for his review" | Decided; LDZ-DDR-001 v0.2 |
| D6 budget | Sign outside the budget; budget covers the two-puck kit | `budget_usd` $120 | $120 (unchanged; scope already redefined in R13); kit $114.00 |
| O2 R4 | Gateway within 300 m of the bay | 1 km target; -6.0 dB margin; not met | 300 m target; 353 m range at SF9 with 10 dB fade margin; met on paper |
| O3 R6 | Two-part road-marker epoxy; R6 restated around maneuvering wheels | Bitumen pad or epoxy; parked-wheel finding not in R6 | Epoxy bed (BOM line 7, $4.00 unchanged); R6 restated; bond factor 0.66 unchanged, still at risk |
| O4 R11 | Daylight-only legibility | 25 m by day and night; not met | 25 m by day; about 28 m; met on paper |
| O5 Sign network | Private network server (TwinKit) or a permissive city network | Proposed | Decided constraint in precis and problem statement |
| O6 Engineering proposals | Diode per cell, 85 °C pulse capacitor, full potting, 6 mm crown radius | Awaiting confirmation | Confirmed; no geometry or cost change |
| O7 Payload | 11 bytes if the band is US915 | Proposed | Decided firmware rule; [A2] 370.7 ms at SF10; firmware itself on hold (TRL 4) |

Also updated to match FieldNode's published figure (FND-DDR-002): the sign's 17.7 mW is now checked against 100 mW only (was 115 mW and 100 mW).

Files changed: LDZ-PRB-001 v0.4, LDZ-PRC-001 v0.4, LDZ-REQ-001 v0.4, LDZ-CAL-001 v0.2 (`docs/04-calcs/sizing.py` and `results.csv` re-run), LDZ-DDR-001 v0.2, new LDZ-DDR-002 v0.1; `bom/bom.csv` and `bom/bom-notes.md`; `cad/src/model.py` (comment only; STEP and STL re-exported); `cad/src/sheets.py` and LDZ-DWG-001 at Rev P2 (material note and two notes; geometry unchanged); `cad/src/concept_media.py` (blueprint key figure and exploded-view label; all of `media/` re-rendered and checked); `README.md` (key figures, components, "What sparked the idea"); `project.yaml` (evidence list); all PDFs in `docs/pdf/` rebuilt. Pitch and problem unchanged; no rewording was recommended.

### Requirement status (LDZ-CAL-001 v0.2)

None not met (was 2), 3 at risk, 1 not verifiable at TRL 3, 7 met on paper (was 5), 4 met by design.

| ID | Status | Key number |
| --- | --- | --- |
| R1 Detection | At risk | Weak-steel truck 3.85 µT against a 3 µT threshold; calibration assumed |
| R5 Airtime | At risk | 25.5 s/day at SF9; 51.0 s at SF10 |
| R6 Traffic | At risk | Epoxy bond shear 1.51 MPa against about 1.0 MPa assumed (factor 0.66) |
| R14 Install time | Not verifiable at TRL 3 | Needs an install trial |
| R2, R3, R4, R7, R11, R12, R13 | Met on paper | 38.6 s worst; 7.7 years; 353 m against 300 m; 31 mm; about 28 m by day; 17.7 mW against 100 mW; $114.00 |
| R8, R9, R10, R15 | Met by design | Unchanged |

### Still awaiting Amish

1. **O1, first trial partner and LoRaWAN band.** No recommendation was made. Proposed, awaiting Amish. The US915 payload rule (O7) applies only if that band is chosen.

### Cross-repo actions (other repos not edited)

- **TwinKit:** its network stack must support LoRaWAN class C downlinks, about 200 a day for each LoadZone sign (O5). TwinKit's review does not yet mention class C.
- **FieldNode:** none required. LoadZone now uses FieldNode's published 100 mW allowance and $126.00 core cost, and a 12-byte (or 11-byte in US915) payload, shorter than FieldNode's 20-byte reading.

### README and inspiration

"What sparked the idea" now traces the design to San Francisco's SFpark pilot and the SFMTA Parking Sensor Data Guide (2013), which records in-ground magnetometer sensors whose batteries, meant to last about five years, began failing about a year early; the earlier text about a September 2026 review of research areas was removed. No other file attributed the idea to a review.

### TRL 4

TRL 4 remains on hold by Amish's instruction. The bond pull-off and shear test on asphalt, a field link survey, a magnetometer log under parked vehicles and the payload firmware are decided or recommended but not started.

## Session 2026-09-26: sources strengthened

Sources in the README were checked against the standard of 2026-09-26 ("Fix the weaker sources"); every kept link was fetched and confirmed.

| Where | Old source | New source |
| --- | --- | --- |
| Region table, European Union | gdpr-info.eu (unofficial reproduction of GDPR Article 25) | Regulation (EU) 2016/679, Article 25, on EUR-Lex |
| Region table, India | None (uncited claim about few formal loading bays) | DPIIT, Guidelines for Preparing City Logistics Plan (row rewritten to what the guidelines say about loading lots and per-bay use data) |
| Region table, Mexico and Brazil | None (uncited) | Row replaced by Brazil: CET São Paulo page listing 1,749 on-street truck loading bays |
| What sparked the idea | SFMTA Parking Sensor Data Guide (kept) | Same source; wording corrected to note that noise-filtering software had cut the expected battery life to about three years before the early failures |

No budget change in this session.

## Session 2026-09-26: product appearance model and photoreal renders

Amish chose this repo for the first batch of product renders on 2026-09-26. This session adds an appearance model for photoreal renders; the render images themselves are produced later by the portfolio orchestrator.

### What was added

- `cad/src/product_model.py`: `product_parts()` (33 parts: 5 shell, 12 internal, 10 accessory, 6 context), `TITLE` and `RENDER_VIEWS` (hero, exploded and detail). It imports `PARAMS`, `derived()` and `build_parts()` from `cad/src/model.py`, so every main dimension and interface is unchanged.
- Puck: the model.py dome with a softened foot, a mold parting line, 24 radial anti-skid grooves on the flank, and a recessed crown badge ("LOADZONE BAY SENSOR") with a teal accent ring; the base disc with softened edges; the epoxy bed with a rounded squeeze-out bead; clear amber potting; cells with end caps; the pulse capacitor; the radio carrier board with a shielded module, flash, regulator, diodes and u.FL connector; the magnetometer breakout with its IC and header; the flexible antenna with a copper trace pattern.
- Sign option: rounded, painted sign face with a raised "LOADING ZONE" legend, border and teal band; a filleted display housing with a polycarbonate window over the e-paper panel showing "2 FREE BAYS" and an arrow; a cable gland; band clamps with ears, clamp bolts and face bolts.
- Context (neutral colours): an asphalt road patch with a white bay edge line and slot end line, a kerb stone, sidewalk paving and a short section of the existing street pole.
- README: hero image now points to `media/render-hero.png`, with a link to `media/render-exploded.png`.

### Where the appearance model differs from model.py

1. **Render layout.** In the hero view the kerb is drawn 400 mm from the puck (installed 1.3 m) and the sign's lower edge 250 mm above the sidewalk (installed 2.1 m), so the puck and sign read in one frame; the view note says so. Proposed, awaiting Amish. Recommendation: accept for the hero render, and keep the true layout in the concept hero and the drawing.
2. **Dome surface detail.** The anti-skid grooves (about 1.1 mm deep), parting line (0.45 mm) and crown badge recess (1.0 mm) are cut into the 4 mm cast wall. Proposed, awaiting Amish. Recommendation: accept as appearance only, and check the local wall and the wheel-load path when the mold is designed.
3. **Potting colour.** The potting is shown as a clear amber polyurethane so the internals read in the exploded render; the BOM does not set a colour. Proposed, awaiting Amish. Recommendation: treat clear potting as a render convention unless a clear grade suits the budget.
4. **Sign artwork.** The legend, "FREE BAYS" label, teal band and e-paper image are placeholder artwork. Proposed, awaiting Amish. Recommendation: set the final legend to the local traffic sign rules of the first trial city (O1).
5. **Host FieldNode.** The host FieldNode (BOM 11) above the sign is left out of the renders to keep the frame compact; only the cable gland hints at its supply. Proposed, awaiting Amish. Recommendation: accept, and mention the FieldNode in the render caption.
6. **Minor.** The flexible antenna is drawn 0.6 mm thick (1.0 mm envelope in model.py), the display housing is filleted with a window pocket, and the clamps gain bolt ears. The exploded view shows the puck only, because the 600 mm sign would dwarf the 150 mm puck.

### Status

This is an appearance model only: no tolerances, PCB layouts or fabrication detail were added. `trl` stays 3, and TRL 4 remains on hold. No budget change in this session.

## Session 2026-09-27: kit 1.5.0 and image quality

- Kit 1.5.0 synced: STANDARDS v1.5 (sections 12 to 15: product renders, storefront images and image quality, public release, authorship and signing), `.kit/cards.py`, `.kit/image_qc.py`, `.kit/release_gate.py`, issue templates, and the `/render-product` and `/release` commands. `CLAUDE.md` now matches `.kit/CLAUDE.md`.
- Every `media/render-*.png` recaptioned from its original render with the new layout: the title, concept label and repository sit in a band above the render and the view note in a band below it, each line wrapped to the image width, so no text overlaps other text or the render or runs off the image. `media/card.png` and `media/social-preview.png` regenerated with the same rules.
- `python .kit/image_qc.py` and `python .kit/release_gate.py` pass. trl stays 3.

## Session 2026-10-01: design for construction and prototype build plan (kit 1.7.0)

### What was done

- Kit 1.7.0 installed (`.kit/`, `.claude/commands/`); `CLAUDE.md` now matches `.kit/CLAUDE.md`.
- Constructability review of every part, with build123d checks in `cad/src/model.py` (`python cad/src/model.py --check`): 92 checks, all pass. The model now also builds the dome casting tooling (`build_tooling`) and a sign mount that can be made and fitted.
- `docs/decisions/0003-design-for-construction.md` (LDZ-DDR-003 v0.1, Draft): every change, made under Amish's 2026-09-30 instruction to make the design physically buildable; open for his review.
- `docs/05-build-plan.md` (LDZ-BLD-001 v0.1): the illustrated prototype build plan, with 7 making sketches (`cad/drawings/LDZ-DWG-101` to `107`), 8 joint close-ups, 9 step pictures, a tray layout, a sign face drilling layout and a wiring diagram (`docs/05-build-plan/`), all drawn by `cad/src/build_plan_media.py`.
- `docs/06-design-decisions.md` (LDZ-DEC-001 v0.1): 10 open decisions, 7 items to confirm when parts are bought, a value-engineering section and the decisions made.
- `bom/bom.csv`: lines 1, 3, 6, 9, 10 and 12 re-specified, line 13 (one-off casting tooling) added; `bom/bom-notes.md` updated.
- Calculations re-run on the constructable design: LDZ-CAL-001 v0.3 (`docs/04-calcs/sizing.py` now reports cost against the value-engineering target); LDZ-REQ-001 v0.5 and LDZ-PRC-001 v0.5 updated to match.
- STEP and STL regenerated (puck, dome, base tray, sign option, dome tooling); general arrangement LDZ-DWG-001 Rev P3; concept media regenerated (`python cad/src/concept_media.py`).
- `project.yaml`: `design_state: constructable`; build plan, register, DDR-003 and the picture script added to `trl_evidence`. `budget_usd` unchanged at 120.
- `README.md`: value-engineering wording in the header, "Prototype build plan" and "Design decisions" links, and a "Building the prototype" section before "Safety".

### Design changes made for construction (LDZ-DDR-003)

1. Base: a printed tray with a tapered locating ring for the dome, an 8 mm fill hole and four 4 mm vents; the seam is sealed and the puck is potted upside down.
2. Inside the puck: cradles for the cells, four board standoffs and an antenna rib printed on the tray; the capacitor and antenna stand on the tray.
3. Cells moved 3 mm and the capacitor with them toward the centre (2.5 mm from the dome wall, was 1.2 mm).
4. Antenna moved 2 mm inward onto the rib (3.8 mm from the dome wall, was 1.9 mm).
5. Dome casting: printed mould master, silicone mould and printed core plug with flange, skirt and overflow holes (BOM line 13).
6. Programming pads on the radio board and a programming and bench-test hold point before the dome goes on; the board is prototyping board.
7. Sign mount: two aluminium channel brackets bolted to the sign, with stainless band clamps through slots in their flanges, in place of solid rings; sign 33 mm off the pole (was 30); brackets 100 mm from the sign's ends (was 120).
8. Display housing: a bought enclosure with a clear lid, screwed from behind the sign, with an M20 gland through the sign face.

### Key results

- Mass unchanged at 451 g without the bed; height 31 mm; loads, link, energy and detection figures unchanged.
- Value-engineering target: USD 120. Estimated cost of the constructable design: USD 116 for the two-puck kit (USD 4 under the target). Sign option USD 101 (was 97) plus a USD 126 FieldNode; one-off tooling USD 35.
- Requirement status unchanged: none not met, 3 at risk (R1, R5, R6), 1 not verifiable at TRL 3 (R14), 7 met on paper, 4 met by design.

### Proposed, awaiting Amish

All are in `docs/06-design-decisions.md`. New this session: acceptance of LDZ-DDR-003 (item 1), a sealed-for-life puck with over-the-air updates (item 3), the base tray material for the epoxy bond (item 4) and fixings showing on the sign face (item 5).

### Safety concerns

- Potting over live Li-SOCl2 cells: use a low-exotherm grade and check its peak temperature (build plan stop S4).
- Polyurethane casting and potting involve isocyanates: ventilation and a suitable respirator (stop S3).

### Stale media (made on Amish's Mac; not regenerated here)

- `cad/src/product_model.py` still draws the concept's ring clamps (it reads the clamp band width and thickness, now 12 and 0.8 mm), and its puck internals use the old cell and antenna positions. The photoreal renders that show the sign (`media/render-hero.png` and any other `media/render-*.png` with the sign) and `media/card.png` and `media/social-preview.png` are stale for the sign mount; the puck's outside is unchanged.

### Recommended next step

Amish's review of LDZ-DDR-003 and the open decisions in LDZ-DEC-001, then the product model and renders updated on the Mac. TRL 4 (building to this plan) remains on hold.

## Session 2026-10-02: open decisions decided

On 2026-10-02 Amish approved every recommendation written for the open decisions: "i approve your recommendations for all 555 open decisions." trl stays 3; nothing was built or tested.

### Decisions recorded

10 decisions recorded in the design decisions register (LDZ-DEC-001, Decisions made, dated 2026-10-02): LDZ-DDR-003 accepted as made (1); first partner type and US915 as the default band (2), the first candidate to approach and not an agreed partner; sealed-for-life puck with over-the-air updates at TRL 4 (3); printed ASA tray sanded with 80 grit (4); button heads on the sign face (5); placeholder legend until the city is chosen, then the city's rules and traffic engineer approval (6); surface puck only, not for plowed streets, cored version later (7); dome detail appearance only (8); amber potting a render convention (9); render layout accepted with FieldNode in the caption (10).

### Documents changed

- `docs/06-design-decisions.md` (LDZ-DEC-001 v0.2): all 10 open items moved to Decisions made; Open decisions now reads "None"; item 7 of "To confirm when parts are bought" updated for the tray material.
- `docs/decisions/0003-design-for-construction.md` (LDZ-DDR-003 v0.2): status line and Table 3 record acceptance of Tables 1 and 2 and A1 to A3; status stays Draft.
- `docs/decisions/0002-recommendations-accepted.md` (LDZ-DDR-002 v0.2): O1 recorded as decided.
- `docs/decisions/0001-trl2-review-decisions.md` (LDZ-DDR-001 v0.3): O1 recorded as decided.
- `docs/02-concept.md` (LDZ-PRC-001 v0.6): surface puck not for plowed streets; sealed for life; US915 default; partner; legend rule before street mounting; open questions closed.
- `docs/01-problem.md` (LDZ-PRB-001 v0.5): first partner type; surface puck not for plowed streets.
- `docs/03-requirements.md` (LDZ-REQ-001 v0.6): band assumption updated to US915 by default; no status changed.
- `docs/05-build-plan.md` (LDZ-BLD-001 v0.2): sign face: placeholder legend and the approval rule before street mounting.
- `project.yaml`, `README.md` and `CITATION.cff`: pitch reworded to "A curbside loading bay occupancy sensor for streets that are not plowed: ..."; README safety and build sections updated.
- `bom/bom-notes.md`: decided material and part choices noted; the line 4 band change is a follow-up.
- PDFs re-rendered with `python .kit/render.py`; superseded versions removed.

No CAD model, BOM quantity or price, or picture was changed. Requirement status is unchanged: none not met, R1, R5 and R6 at risk, R14 not verifiable at TRL 3.

### Follow-up actions to carry approved decisions into the design

1. Decision 2 (bom): Change BOM line 4 (antenna) to the US915 band and check its price.
2. Decision 2 (calcs): Rerun LDZ-CAL-001 airtime, latency and duty-cycle figures (sections on airtime and latency, R2, R3, R5) for US915 rules with the 11-byte payload, replacing the EU868 figures.
3. Decision 3 (docs): Plan over-the-air firmware updates in the TRL 4 work list when TRL 4 is opened (not now; TRL 4 is on hold).
4. Decision 6 (pictures): Draw the sign legend to the trial city's sign rules (MUTCD in the US) once the city is chosen, and update BOM line 8 and the sign renders.
5. Decision 10 (pictures): Add a mention of the host FieldNode to the render captions (`media/render-*.png`) when the renders are next made on Amish's Mac.
6. Decision 1 (pictures): Update `cad/src/product_model.py` and the photoreal renders, `media/card.png` and `media/social-preview.png`, which still show the concept's ring clamps on the sign.

### Points found in the review

- The value-engineering section prices the host FieldNode at USD 126; FieldNode's constructable design is now USD 139 (FieldNode concept and NoiseMap register).
- Item 7 is effectively a scope statement for the pitch: the product as designed cannot be used where streets are ploughed.

### Safety

The surface puck is now stated not to be for plowed streets. A sign must not go on a street until its legend follows the city's sign rules and the city traffic engineer has approved it. The road-work, lithium cell and resin warnings are unchanged.

### Recommended next step

Rerun the radio calculations for US915 and update BOM line 4. TRL 4 remains on hold by Amish's instruction.

## Session 2026-10-02: approved follow-ups carried out

Amish approved all follow-up actions from the open-decision sign-off on 2026-10-02. trl stays 3; nothing was built or tested.

### Approved follow-ups carried out

1. Decision 2 (bom): done. BOM line 4 is now a 915 MHz (US915) flexible antenna; price unchanged at USD 3.00, indicative, same class as the 868 MHz part (`bom/bom.csv`, `bom/bom-notes.md`).
2. Decision 2 (calcs): done. `docs/04-calcs/sizing.py` and LDZ-CAL-001 v0.4 rerun for US915 with the 11-byte payload: no duty cycle, 400 ms dwell limit (SF10 at 370.7 ms is inside it), uplinks SF7 to SF10 only, 915 MHz link. Airtime 25.5 s a day at SF9 and 46.0 s at SF10; worst report time 18.2 s at SF9 (was 38.6 s); cell life 7.7 years at SF9, 6.2 at SF10; SF9 range 342 m (was 353 m), 1.14 times the 300 m target.
3. Decision 3 (docs): not done: over-the-air update planning belongs to the TRL 4 work list, and TRL 4 is on hold.
4. Decision 6 (pictures): not done: the trial city is not chosen, so the sign legend cannot be drawn to its rules; BOM line 8 and the sign renders wait for that choice.
5. Decision 10 (pictures): not done: render captions are made with the photoreal renders on Amish's Mac.
6. Decision 1 (pictures): done for the appearance model: `cad/src/product_model.py` now takes the channel brackets, band clamps, button-head bolts and nyloc nuts straight from `build_sign()` in `model.py`, and the antenna height and board standoff height from the model. Photoreal renders, `media/card.png` and `media/social-preview.png` are not made here (Mac).

### Requirement status changes

None. R2 now reads "Met on paper" at every US915 rate (it was "at SF10 or faster"); R5 is at risk (not met at SF10); R4 stays met on paper at 342 m.

### Cost and mass

Two-puck kit USD 116.00 against the value-engineering target of USD 120 (USD 4.00 under the target); `budget_usd` unchanged. The host FieldNode on BOM line 11 is now shown at USD 139.50 (FND-CAL-001 base node, was USD 126.00), so a bay with the sign is USD 356.50 (was USD 343.00). Puck mass is unchanged at 451 g without the pad.

### Documents changed

- `docs/04-calcs/01-sizing.md` (LDZ-CAL-001 v0.4), `docs/04-calcs/results.csv`, `docs/04-calcs/sizing.py`.
- `docs/02-concept.md` (LDZ-PRC-001 v0.7), `docs/03-requirements.md` (LDZ-REQ-001 v0.7), `docs/05-build-plan.md` (LDZ-BLD-001 v0.3: antenna band, 11-byte airtime check), `docs/06-design-decisions.md` (LDZ-DEC-001 v0.3: FieldNode price), `docs/decisions/0003-design-for-construction.md` (LDZ-DDR-003 v0.3: appearance model note).
- `README.md`, `bom/bom.csv`, `bom/bom-notes.md`.
- Drawing LDZ-DWG-001 is now Rev P4; concept media regenerated with the new key figures (`media/hero.png`, `concept-blueprint`, `cutaway.png`, `exploded.png`, `flow.png`, `model.glb`).
- The model and the build plan pictures are unchanged: no geometry changed, so STEP, STL and the 21 build plan pictures were not regenerated.

### Render scenes

Exported to `/home/claude/renders/loadzone`: hero, exploded and detail (one .npz and .json each, plus `loadzone__jobs.json`). The renders themselves, captions with FieldNode named, `card.png` and `social-preview.png` are made next on Amish's Mac.

### Cross-repo actions

- FieldNode: confirm that USD 139.50 is the base-node price LoadZone should quote (FND-CAL-001); LoadZone line 11 now follows it.

## 2026-10-02: photoreal renders redone on the constructable design

Rendered with Blender Cycles on Amish's Mac from the updated appearance model; captioned with `.kit/photo_caption.py`; `media/card.png` and `media/social-preview.png` regenerated with `.kit/cards.py`. Views: hero, exploded, detail. image_qc passes. Appearance deviations are those logged above as proposed, awaiting Amish.

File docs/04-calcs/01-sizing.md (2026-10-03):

---
doc_id: LDZ-CAL-001
title: LoadZone sizing calculations
project: LoadZone
doc_type: Calculation note
version: "0.4"
status: Draft
date: '2026-10-02'
author: Amish Chadha
license: CERN-OHL-S-2.0
revisions:
- version: "0.1"
  date: '2026-09-25'
  author: Amish Chadha
  change: First TRL 3 sizing note (airtime, energy and cell life, latency, link, detection, loads, size and mass, sign option, cost) with a status for every requirement
- version: "0.2"
  date: '2026-09-25'
  author: Amish Chadha
  change: Recommendations accepted by Amish (DDR-002)
- version: "0.3"
  date: '2026-10-01'
  author: Amish Chadha
  change: Constructable design (LDZ-DDR-003) re-run; cost reported against the value-engineering target
- version: "0.4"
  date: '2026-10-02'
  author: Amish Chadha
  change: Airtime, latency, duty cycle and link rerun for US915 with the 11-byte payload (LDZ-DEC-001 item 2); antenna line 4 at 915 MHz; FieldNode priced at USD 139.50; no requirement status changed
---

# LoadZone sizing calculations

On paper, LoadZone meets eleven of its fifteen requirements (seven by calculation, four by design), has three at risk and leaves one that only an installation trial can settle; none is now not met. Version 0.2 applies Amish's decisions of 2026-09-25 (LDZ-DDR-002). **R4**, restated as a gateway within 300 m of the bay, is met on paper: from road level under a parked van a puck reaches about 342 m in a street canyon at SF9 with a 10 dB fade margin (it was not met against the TRL 2 target of 1 km). **R11**, restated as daylight only, is met on paper at about 28 m (it was not met at night). R1 (detection), R5 (airtime at slow data rates) and R6 (bond under braking, now with a two-part epoxy bed) are at risk. The core numbers of the TRL 2 concept stand or improve: cell life is 7.7 years at SF9, the worst-case report time is 18.2 s, and the two-puck kit is estimated at USD 116.00 against a value-engineering target of USD 120. Version 0.3 re-ran every figure on the constructable design of LDZ-DDR-003 (base tray, cradles, moved cells and antenna, channel brackets on the sign): mass, loads, link and energy were unchanged, and only the cost moved. Version 0.4 applies Amish's decision of 2026-10-02 that US915 is the default band (LDZ-DEC-001, item 2): airtime, latency and the duty-cycle rules are rerun for US915 with the 11-byte payload, and the link at 915 MHz. No requirement changes status; the worst-case report time falls from 38.6 s to 18.2 s because US915 has no duty-cycle wait, and the range at SF9 falls from 353 m to 342 m.

Every number in this note is printed by `docs/04-calcs/sizing.py`; the tag in brackets, for example [B2], is the line of the script's output that carries it. Run it from the repo root with `python docs/04-calcs/sizing.py`; it also writes `docs/04-calcs/results.csv`. The script imports `PARAMS`, `derived()` and the part volumes from `cad/src/model.py`, so the geometry here is the geometry in the STEP files and in drawing LDZ-DWG-001. It reads the costs from `bom/bom.csv` and `budget_usd` from `project.yaml`, which is a hypothetical value-engineering target, not a spending limit. All values are first-principles estimates; nothing is measured.

> **Safety:** These are paper estimates. They do not show that a puck is safe to leave in a roadway, that the primary lithium cells are safe in a hot road, or that the bond will hold. Bond strength, cell temperature and crush behavior must be checked on hardware before any puck is installed, and only under a road permit with traffic management. See LDZ-PRC-001, Safety.

## 1. Assumptions

*Table 1. Inputs. All are assumptions for a paper design unless a source is given.*

| Input | Value | Basis |
| --- | --- | --- |
| Traffic | 100 state changes a day per puck plus hourly heartbeats: 124 uplinks | LDZ-REQ-001 R3 |
| Payload | 11 bytes plus 13 bytes of LoRaWAN overhead, 125 kHz, CR 4/5 (US915 default band; 11 bytes is the most the slowest US915 rate carries) | LDZ-PRC-001; LDZ-DDR-002; LDZ-DEC-001 item 2 |
| Radio currents | 45 mA transmit at +14 dBm, 4.6 mA receive, 8 mA controller awake 0.5 s per uplink, two 0.1 s receive windows | Same as FND-CAL-001 |
| Sleep and sampling | 6 µA sleep; one reading a second, 10 ms awake at 2 mA | LDZ-PRC-001 v0.2 |
| Cells | 2 x 2.6 Ah in parallel, derated 40 % for cold, pulse loads, self-discharge and end-of-life voltage | ER14505 class, typical rating |
| Fair use | 30 s of uplink airtime and 10 downlinks per node per day on The Things Network | [TTN](https://www.thethingsnetwork.org/docs/lorawan/duty-cycle/), checked 2026-09-25 |
| Band rules | US915: no duty cycle; a transmission may not exceed 400 ms of dwell time on a 125 kHz channel; uplink rates SF7 to SF10 only (SF11 and SF12 are not offered); the RX2 window is SF12 on 500 kHz | LoRaWAN regional parameters for US902-928; FCC 47 CFR 15.247 |
| Link | Puck antenna -2 dBi once potted; 10 dB road-level loss; 10 dB (typical) to 20 dB (worst) for a van overhead; gateway 10 m high, 2 dBi, 2 dB feeder loss; 6 dB noise figure | Estimates; FND-CAL-001 for the gateway side |
| Path loss | 3GPP TR 38.901 urban microcell street canyon (UMi), Table 7.4.1-1, at 915 MHz with the user height at its 1.5 m floor; the road-level loss covers the lower antenna | Standard model, used outside its height range |
| Detection | A vehicle is a line of vertical induced dipoles along its length; 10 µT under the middle of a parked van (calibration); 3 µT threshold, 10 times the magnetometer's 0.3 µT RMS noise | Assumption; only a field log can set these |
| Loads | Half of a 10 t single axle (49 kN), x1.3 dynamic; friction 0.7; rigid cast polyurethane 40 MPa and semi-rigid potting 15 MPa in compression; two-part road-marker epoxy to asphalt shear 1.0 MPa at 20 °C, 0.2 MPa at 50 °C | Typical values, to be checked against chosen materials |
| Vehicles | Bay 2.6 m wide; van 2.0 m wide, 1.75 m track, 225 mm tires; car 1.8 m, 1.55 m, 200 mm | Typical dimensions |
| Sign | Class C receiver on at 15.2 mW; 200 redraws a day at 26.4 mW for 5 s plus the controller; 90 % rail efficiency; 7.5 in panel with a 97.9 mm active height, digits 80 % of it | Typical 7.5 in panel data |
| Legibility | 30 ft of distance per inch of letter height (0.36 m per mm) | MUTCD, section 2A.13 |

## 2. Airtime (R5)

An 11-byte uplink is on air for 61.7 ms at SF7, 205.8 ms at SF9 and 370.7 ms at SF10, the slowest rate US915 offers on 125 kHz [A1]. At SF10 that is inside the 400 ms dwell limit, which a 12-byte payload (411.6 ms) would break, so the 11-byte rule is what lets the slowest US915 rate work at all [A2]. At 124 uplinks a day the airtime is 7.7 s at SF7, 14.0 s at SF8 and 25.5 s at SF9, all within the 30 s fair-use limit, but 46.0 s at SF10 [A1]. At SF10 even the state changes alone exceed the limit: 81 uplinks a day is the most that fits. SF11 and SF12 are not offered on US915 uplinks, so the 102 s and 184 s of the EU868 figures no longer arise. **R5 is at risk**: met at SF7 to SF9, not met at SF10. With the 11-byte payload SF9 fits with hourly heartbeats, so the 2 h heartbeat fallback is not needed at SF9. A private gateway (TwinKit) is not bound by the community fair-use limit, and US915 has no duty cycle that would limit it.

## 3. Energy and cell life (R3)

At SF9 a puck uses 1.11 mAh a day: 0.144 mAh asleep, 0.480 mAh for sampling (20 µA average) and 0.488 mAh for 124 uplinks at 14.2 mA·s each [B1, B2]. That is 0.406 Ah a year against 3.12 Ah usable, **a life of 7.7 years, and R3 is met** [B2, B3]. Sampling and uplinks each take about 44 % of the budget [B3], so a slower sampling rate is the first lever if life must grow. Life is 9.6 years at SF7 and 6.2 years at SF10 [B2], the slowest US915 rate, so R3 holds at every rate US915 offers, but pucks at SF10 still fail R5.

**Pulse supply.** One SF9 uplink draws 9.3 mC; if the capacitor supplied it alone with 0.3 V of droop it would need 31 mF, and 56 mF at SF10 [B4]. Bobbin Li-SOCl2 cells cannot deliver 45 mA pulses well, so the capacitor is essential. Ordinary supercapacitors are often rated only to 60 to 70 °C, below the road-surface target, so the BOM now calls for an 85 °C hybrid pulse capacitor.

**Supply voltage.** Fresh Li-SOCl2 cells sit at about 3.67 V open circuit, above the 3.6 V recommended maximum of STM32WL-class modules. One Schottky diode per cell brings this to 3.42 V and also stops one cell charging the other, which primary lithium cells must never do [B5]. This is an engineering proposal (LDZ-DDR-001, O6).

## 4. Report latency (R2)

A new state must hold for 15 s, sampling adds up to 1 s and the network path about 2 s, so a report reaches the server in 17.7 s typically at SF9 [C1]. US915 has no duty-cycle wait after the previous uplink (the EU868 rule that added 20.4 s at SF9 and gave a worst case of 38.6 s), so the worst case is 18.2 s at SF9 and 18.4 s at SF10 [C1]. A retry on another channel after a lost uplink would add about a second and a half at most [C1]. **R2 is met on paper** at every rate US915 offers; the SF11 and SF12 cases of the EU868 figures cannot occur.

## 5. Link from road level (R4)

With 11.5 dBm EIRP the link budget at SF9 is 141.0 dB [D1, D2]. At 915 MHz the UMi model gives 127.5 dB of non-line-of-sight path loss at 1 km to a 10 m gateway, and 118.5 dB in line of sight [D1]. Adding 10 dB for an antenna at road level and 10 dB for a van overhead leaves **-6.4 dB at 1 km out of sight and 2.6 dB in line of sight; with the worst vehicle loss, -16.4 dB** [D2]. The range out of sight is 657 m with no fade margin and 342 m with 10 dB [D2]. SF10, the slowest US915 rate, would reach 403 m with the fade margin [D2] but breaks R5. The 1 km target of versions up to LDZ-REQ-001 v0.3 is not met. Under LDZ-DDR-002 (O2) R4 is restated as a gateway within 300 m of the bay; 342 m is 1.14 times that distance [D3], so **R4 is met on paper**, with a thin margin that a field survey must confirm. The UMi model is used below its 1.5 m height floor; the 10 dB road-level loss is the estimate that covers this and only a field survey can settle it.

## 6. Detection (R1)

With the line-dipole model calibrated to 10 µT under a parked van, a car gives 10.6 µT, a small car pushed to one end of the 7 m slot 10.5 µT, a high-chassis box truck 7.7 µT and a box truck with little steel low down 3.85 µT, just 1.28 times the 3 µT threshold [E1]. A van passing in the next lane gives 0.46 µT and a van parked in the next slot 0.08 µT, both well below the threshold [E1]. The geometry therefore favors the slot-center position (D3): vehicles anywhere in the slot are seen, and neighbors are not. The margins rest on the 10 µT calibration, which is an assumption. **R1 is at risk and not verifiable at TRL 3**; high-clearance trucks are the weak case, and a short field log under parked vehicles would settle it.

## 7. Loads and bond (R6)

The load basis is now set: half of a 10 t single axle, 49.0 kN static, or 63.8 kN with a 1.3 dynamic factor for slow maneuvering [F1]. If the whole wheel bears on the 92 mm flat crown, the stress is 7.38 MPa static and 9.59 MPa dynamic; spread over the base it is 2.78 MPa [F1]. That gives factors of 5.4 (static) and 4.2 (dynamic) on rigid cast polyurethane, but only 2.0 and 1.6 on the potting under the crown [F2]. The bond is weaker: with a friction coefficient of 0.7 the tire can push 34.3 kN sideways, 1.51 MPa over the 170 mm pad, against an assumed adhesive-to-asphalt strength of 1.0 MPa at 20 °C (factor 0.66) and 0.2 MPa at 50 °C (0.13) [F3]. The bed is now two-part road-marker epoxy rather than a bitumen pad (LDZ-DDR-002, O3), so the 1.0 MPa figure is the epoxy-to-asphalt value, in which the asphalt surface usually governs. These are upper bounds, since a truck tire deflects around a 31 mm puck and rarely brakes on it. Wheel geometry helps: a van or car parked inside the bay lines keeps its nearest tire edge at least 462 mm (van) or 275 mm (car) from the puck axis, against a 75 mm puck radius, so parked wheels straddle the puck and only maneuvering wheels cross it [F4]. R6 is restated with this finding (LDZ-DDR-002, O3): the load case is a maneuvering wheel crossing the puck, and the slot-center placement keeps it out of parked wheel paths. **R6 is still at risk** on debonding under braking; crushing is met on paper. The pull-off and shear test on asphalt that would settle it is TRL 4 work and on hold.

## 8. Size and mass (R7)

The model gives a puck 31.0 mm high on a 150 mm base, a 170 mm pad, a 104 mm crown and a 6 mm crown radius [G1]. **R7 is met.** From the model volumes the puck weighs 451 g without its pad, and the pad 75 g [G2]; the TRL 2 estimate of 0.35 kg is corrected, because the cavity is now fully potted.

## 9. Sign option (R11, R12)

**Power (R12).** The class C receiver draws 15.2 mW, or 0.364 Wh a day, and 200 redraws add 0.015 Wh; with 90 % rail efficiency the sign draws 0.424 Wh a day, or 17.7 mW [H1]. That is 18 % of FieldNode's allowance of 100 mW, which FieldNode now publishes (FND-DDR-002) [H2]. **R12 is met on paper.** The sign takes about 200 downlinks a day, against The Things Network's limit of 10 [H5], so D7 works only on a private network server such as TwinKit, where the downlinks use 58 s a day in the US915 RX2 window (SF12 on 500 kHz, 289 ms each), with no duty-cycle limit [H5]. This is decided: the sign option requires a private network server or a city network that allows it (LDZ-DDR-002, O5). Typical 7.5 in e-paper panels are rated for about 0 to 50 °C in operation, so the sign may not refresh on freezing days; this is a limit to confirm with the panel chosen.

**Legibility (R11).** Digits 78 mm high on the 97.9 mm panel read at about 28.2 m by day at full contrast, using the MUTCD legibility index of 0.36 m per mm; 69 mm digits would be enough for 25 m [H4]. E-paper contrast is lower than a printed sign's, so the daytime figure is optimistic. The panel is unlit, and a 0.5 W front light for 12 h a night would add 6.0 Wh a day, 2.5 times the 100 mW allowance [H3]. Under LDZ-DDR-002 (O4) R11 is restated as a daylight-only target of 25 m, so **R11 is met on paper**; at night drivers rely on the data feed.

## 10. Cost (R13)

Value-engineering target: USD 120 (`budget_usd`). Estimated cost of the constructable design: **USD 116.00 for the two-puck kit (USD 4.00 under the target)**; one puck costs USD 54.00 [I1]. The target covers the two-puck kit only (D6). Making the design constructable added USD 2.00 for sealant, screws and mould release (LDZ-DDR-003). The sign option costs USD 101.00 (USD 97.00 before its channel brackets), and its host FieldNode USD 139.50 (the base node, priced in the FieldNode BOM and up from USD 126.00 in version 0.3), for USD 356.50 per bay with the sign; the one-off dome casting tooling, USD 35.00, is not a per-kit cost [I1]. **R13 is met on paper (under the target)**, on indicative prices.

## 11. Requirement status

*Table 2. Requirement status from this note. The same rows are in `docs/04-calcs/results.csv`.*

| ID | Requirement | Value | Target | Status |
| --- | --- | --- | --- | --- |
| R1 | Detect slot state | Van 10.0 µT, high-chassis truck 7.7 µT, weak-steel truck 3.85 µT, next lane 0.46 µT against 3 µT | 97 % correct over a day | **At risk** (not verifiable at TRL 3) |
| R5 | Fair-use airtime | 7.7 s at SF7, 25.5 s at SF9, 46.0 s at SF10 (SF11 and SF12 not offered in US915) | 30 s a day or less | **At risk** (not met at SF10) |
| R6 | Survive traffic | Crown 7.4 MPa, factor 5.4 on PU and 2.0 on potting; epoxy bond shear 1.51 MPa, factor 0.66 at 20 °C | 49 kN maneuvering wheel crossing the puck, no cracking or debonding; parked wheels straddle it | **At risk** (debond under braking) |
| R14 | Quick install | Bonded pad, no road cutting | 15 min per puck | Not verifiable at TRL 3 |
| R2 | Report quickly | 17.7 s typical; 18.2 s worst at SF9, 18.4 s at SF10 (no duty-cycle wait in US915) | 60 s or less | Met on paper |
| R3 | Battery life | 7.7 years at SF9; 6.2 years at SF10 | 5 years or more | Met on paper |
| R4 | Reach a gateway from road level | 342 m NLOS range with a van over and 10 dB fade margin at SF9 | Gateway within 300 m in a street canyon (restated) | Met on paper |
| R7 | Low profile | 31 mm high, 150 mm diameter, 6 mm crown radius, yellow | 35 mm or less, rounded | Met on paper |
| R11 | Sign legible (option) | About 28 m by day at full contrast; unlit at night | 25 m by day (restated, daylight only) | Met on paper |
| R12 | Sign power (option) | 0.42 Wh a day (17.7 mW) against 100 mW | Within the FieldNode allowance | Met on paper (private network only) |
| R13 | Low cost | USD 116.00 for two pucks, USD 4.00 under the target | Value-engineering target USD 120 | Met on paper (under the target) |
| R8 | Weather and temperature | Parts rated -40 to +85 °C with an 85 °C pulse capacitor; fully potted | IP68; -25 to +70 °C | Met by design (sealing not verifiable at TRL 3) |
| R9 | Privacy | Magnetometer only; state, timer, confidence, voltage, temperature | No images, audio or identifiers | Met by design |
| R10 | Open data | CDS Events `park_start`, `park_end`, `scheduled_report`, `comms_lost`, `comms_restored`; Metrics for occupancy and dwell | Maps onto CDS Events and Metrics | Met by design |
| R15 | Tamper resistance | No external fasteners; removal flagged by a field and orientation step | No screws; removal reported | Met by design |

Counts: none not met, 3 at risk, 1 not verifiable at TRL 3, 7 met on paper, 4 met by design [K]. In version 0.1: 2 not met (R4, R11), 3 at risk, 1 not verifiable, 5 met on paper, 4 met by design.

The Curb Data Specification event types used for R10 were checked against the specification's Events API on 2026-09-25 ([Open Mobility Foundation, CDS Events](https://github.com/openmobilityfoundation/curb-data-specification/blob/main/events/README.md)).

## 12. Checks against the TRL 2 figures

*Table 3. TRL 2 claims (LDZ-PRC-001 v0.2) against this note.*

| TRL 2 claim | This note | Action |
| --- | --- | --- |
| About 20 s to report | 17.7 s typical, 18.2 s worst at SF9 (US915) | Precis updated |
| About 1.2 mAh a day, about 7 years | 1.11 mAh a day, 7.7 years at SF9 | Precis updated |
| 72 ms at SF7, 247 ms at SF9; 9 s and 31 s a day | 61.7 ms and 205.8 ms for 11 bytes; 7.7 s and 25.5 s a day | Corrected; R5 now met at SF9 |
| A vehicle overhead leaves room for a gateway a few hundred meters away | 342 m with a 10 dB fade margin | Stands; R4 restated to 300 m and met on paper (LDZ-DDR-002) |
| 2.8 MPa over the base; printed housing would fail | 2.78 MPa over the base, 7.38 MPa at the crown; cast PU adopted | Precis updated; bond is the new risk |
| Sign legible at about 10 m | About 28 m by day at full contrast | Corrected; R11 restated to daylight only and met on paper (LDZ-DDR-002) |
| Sign about 0.4 Wh a day | 0.42 Wh a day drawn | Stands |
| Puck about 0.35 kg | 451 g without pad | Corrected |
| Two-puck kit about $110 | USD 116.00 with the diodes, 85 °C capacitor and construction consumables | Corrected |

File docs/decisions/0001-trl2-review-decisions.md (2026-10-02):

---
doc_id: LDZ-DDR-001
title: LoadZone TRL 2 review decisions
project: LoadZone
doc_type: Design decision record
version: "0.3"
status: Draft
date: '2026-10-02'
author: Amish Chadha
license: CERN-OHL-S-2.0
revisions:
- version: "0.1"
  date: '2026-09-25'
  author: Amish Chadha
  change: Record the TRL 2 review recommendations adopted for TRL 3 work under Amish's 2026-09-25 instruction, and the items that remain open
- version: "0.2"
  date: '2026-09-25'
  author: Amish Chadha
  change: Recommendations accepted by Amish (DDR-002)
- version: "0.3"
  date: '2026-10-02'
  author: Amish Chadha
  change: O1 decided by Amish on 2026-10-02 (LDZ-DEC-001, item 2)
---

# 0001: TRL 2 review decisions

- **Date:** 2026-09-25
- **Status:** accepted for D1 to D8 and O2 to O7. On 2026-09-25 Amish wrote "i accept all your recommendations, go with them across all repos", so every item with a recommendation is decided by Amish, 2026-09-25: go with recommendation (see LDZ-DDR-002). Item O1, which carried no recommendation here, was decided by Amish on 2026-10-02 as recommended in the design decisions register (LDZ-DEC-001, item 2).

## Context

The TRL 2 review note (`docs/REVIEW.md`, session 2026-09-25, /populate) listed nine items as "Proposed, awaiting Amish". Eight carried a recommendation; the ninth (first trial partner and LoRaWAN band) did not. On 2026-09-25 Amish asked for this batch of Design Molecule repos to be taken through the usual process with the instruction "you know the drill, nothing gets past TRL 3". He has not reviewed this repo's items one by one. Every item that carried a recommendation is therefore adopted as recommended for TRL 3 work, open for his review. Items without a recommendation stay open. Version 0.1 recorded nothing as decided by Amish. Version 0.2 records his acceptance of 2026-09-25; LDZ-DDR-002 lists what changed.

## Options considered

The options for each item are those listed in `docs/REVIEW.md` (session 2026-09-25, /populate) and in LDZ-PRC-001 v0.2, Key design choices. They are not repeated here.

## Decision

*Table 1. Items decided by Amish, 2026-09-25: go with recommendation.*

| # | Item | Recommendation | Status |
| --- | --- | --- | --- |
| D1 | Installation | Surface-bonded puck for pilots; a cored in-ground puck stays a later variant | Decided by Amish, 2026-09-25: go with recommendation |
| D2 | Sensing | Magnetometer only for TRL 3; an upward radar stays an option if field data show R1 is missed | Decided by Amish, 2026-09-25: go with recommendation |
| D3 | Granularity | One puck per vehicle slot of about 7 m, at the slot center 1.3 m from the curb face | Decided by Amish, 2026-09-25: go with recommendation |
| D4 | Power | Two AA-size Li-SOCl2 primary cells | Decided by Amish, 2026-09-25: go with recommendation |
| D5 | Housing | Rigid cast polyurethane dome, cavity fully potted in polyurethane, on a flat base | Decided by Amish, 2026-09-25: go with recommendation |
| D6 | Sign option and budget | The sign stays a separate option outside the $120 budget. `budget_usd` is unchanged; the budget is redefined to cover the two-puck bay kit only (R13) | Decided by Amish, 2026-09-25: go with recommendation |
| D7 | Sign data path | LoRaWAN class C downlink from the network server to the sign's host FieldNode | Decided by Amish, 2026-09-25: go with recommendation |
| D8 | Data format | Publish a feed that maps onto the Curb Data Specification Events and Metrics APIs, rather than implementing the specification directly | Decided by Amish, 2026-09-25: go with recommendation |

No reworded pitch or problem line was recommended at TRL 2, so `project.yaml` and `README.md` keep the existing wording. No new `budget_usd` figure was recommended; the $210 and $340 alternatives in the TRL 2 note were options, not the recommendation, and are not applied.

### Items raised at TRL 3

*Table 2. Items raised at TRL 3 and their status after LDZ-DDR-002.*

| # | Item | Status |
| --- | --- | --- |
| O1 | First trial partner (a city curb team, a business district or a carrier) and the LoRaWAN band | **Decided by Amish, 2026-10-02:** first candidate type to approach (not yet agreed), a city curb-management or transportation team that has published or piloted the Curb Data Specification, in a city without routine snow plowing; US915 is the default band, since the 11-byte payload already fits it (LDZ-DEC-001, item 2). LDZ-CAL-001 still uses EU868 figures |
| O2 | R4 link from under a van. LDZ-CAL-001 gives about 350 m in a street canyon at SF9 with a 10 dB fade margin, not 1 km. Options: (a) restate R4 as a gateway within 300 m of the bay, in line of sight where possible; (b) keep 1 km and accept SF12, which breaks R3 and R5; (c) add a relay. Recommendation: (a) | Decided by Amish, 2026-09-25: go with recommendation (a). Applied in LDZ-REQ-001 v0.4 |
| O3 | R6 bond under braking. The upper-bound bond shear (1.51 MPa) exceeds the assumed adhesive-to-asphalt strength. Options: (a) specify two-part road-marker epoxy rather than a bitumen pad; (b) restate R6 with the wheel-path finding that parked wheels straddle the puck; (c) both. Recommendation: (c), with a pull-off test at TRL 4 | Decided by Amish, 2026-09-25: go with recommendation (c). Epoxy bed and restated R6 applied; the pull-off test is TRL 4 and on hold |
| O4 | R11 night legibility. The e-paper sign reads at about 28 m by day but is unlit; a 0.5 W front light needs 2.5 times FieldNode's 100 mW allowance. Options: (a) restate R11 as daylight only; (b) a lit display with its own power; (c) drop the sign in favor of the data feed. Recommendation: (a) | Decided by Amish, 2026-09-25: go with recommendation (a). Applied in LDZ-REQ-001 v0.4 |
| O5 | Sign network. The class C sign takes about 200 downlinks a day, far above The Things Network's 10 a day. Recommendation: the sign option requires a private network server (TwinKit) or a city network that allows it; on The Things Network the sign would need LoRa point to point instead | Decided by Amish, 2026-09-25: go with recommendation |
| O6 | Engineering proposals made at TRL 3: one Schottky diode per cell (parallel cells and the 3.6 V module limit), an 85 °C hybrid pulse capacitor, the fully potted cavity and a 6 mm crown radius | Decided by Amish, 2026-09-25: go with recommendation. Shown in the model and BOM |
| O7 | Payload size. In US915 the slowest 125 kHz rate (SF10) carries at most 11 bytes; the 12-byte payload would not fit there. Recommendation: pack the payload into 11 bytes if the band chosen in O1 is US915 | Decided by Amish, 2026-09-25: go with recommendation (conditional on the band) |

## Consequences

- LDZ-REQ-001, LDZ-PRC-001 and LDZ-PRB-001 moved to v0.3 with this record (and to v0.4 with LDZ-DDR-002): the design choices above are no longer "proposed" in the precis, R6 has a stated load basis, and R13 covers the two-puck kit only.
- The sign option ($97 plus a host FieldNode at $126.00) is costed in the BOM but outside the budget.
- Under LDZ-DDR-002, R4 and R11 are restated and met on paper; R6 is restated and stays at risk until a bond test, which is TRL 4 work and on hold.
- TRL 4 is on hold by Amish's instruction. Nothing in this record starts TRL 4 work.

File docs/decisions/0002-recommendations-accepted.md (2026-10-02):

---
doc_id: LDZ-DDR-002
title: LoadZone recommendations accepted
project: LoadZone
doc_type: Design decision record
version: "0.2"
status: Draft
date: '2026-10-02'
author: Amish Chadha
license: CERN-OHL-S-2.0
revisions:
- version: "0.1"
  date: '2026-09-25'
  author: Amish Chadha
  change: Record Amish's acceptance of all recommendations and what changed in the repo
- version: "0.2"
  date: '2026-10-02'
  author: Amish Chadha
  change: O1 decided by Amish on 2026-10-02 as recommended in LDZ-DEC-001
---

# 0002: Recommendations accepted

- **Date:** 2026-09-25
- **Status:** accepted. Every item below marked "Decided" is decided by Amish, 2026-09-25: go with recommendation. The item without a recommendation (O1) was given one in the design decisions register (LDZ-DEC-001, item 2) and decided by Amish on 2026-10-02: "i approve your recommendations for all 555 open decisions."

## Context

After the TRL 3 session, LoadZone had eight items adopted for TRL 3 work pending Amish's review (LDZ-DDR-001, D1 to D8) and six new items raised at TRL 3 (O2 to O7), each with a recommendation. On 2026-09-25 Amish wrote: "i accept all your recommendations, go with them across all repos." Where a recommendation offered several options, the recommended option is the decision. Items that carried no recommendation are not decided by this record.

## Decision

*Table 1. Items decided by Amish, 2026-09-25: go with recommendation.*

| # | Item | Decision | What changed in the repo |
| --- | --- | --- | --- |
| D1 to D8 | LDZ-DDR-001 items: surface-bonded puck; magnetometer only; one puck per 7 m slot; two AA-size Li-SOCl2 cells; cast polyurethane dome over fully potted electronics; sign outside the $120 budget, which covers the two-puck kit only; LoRaWAN class C downlink to the sign; a feed that maps onto the Curb Data Specification | As recommended in LDZ-DDR-001 | LDZ-DDR-001 v0.2 status wording; LDZ-PRC-001 v0.4 "Key design choices" now decided. `budget_usd` stays $120 (D6 redefined the budget's scope rather than its figure); pitch and problem unchanged, since no rewording was recommended |
| O2 | R4 link from under a van | Option (a): restate R4 as a gateway within 300 m of the bay | R4 in LDZ-REQ-001 v0.4 now reads 300 m, not 1 km; LDZ-CAL-001 v0.2 [D3]: 353 m range at SF9 with a 10 dB fade margin, 1.18 times the distance. R4 moves from not met to met on paper. Precis, problem statement, BOM notes, blueprint key figures and a note on LDZ-DWG-001 Rev P2 |
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

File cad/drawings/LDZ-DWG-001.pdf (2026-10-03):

CONCEPT, NOT FOR FABRICATION | LoadZone · github.com/BoujeeEnjinia1701/loadzone

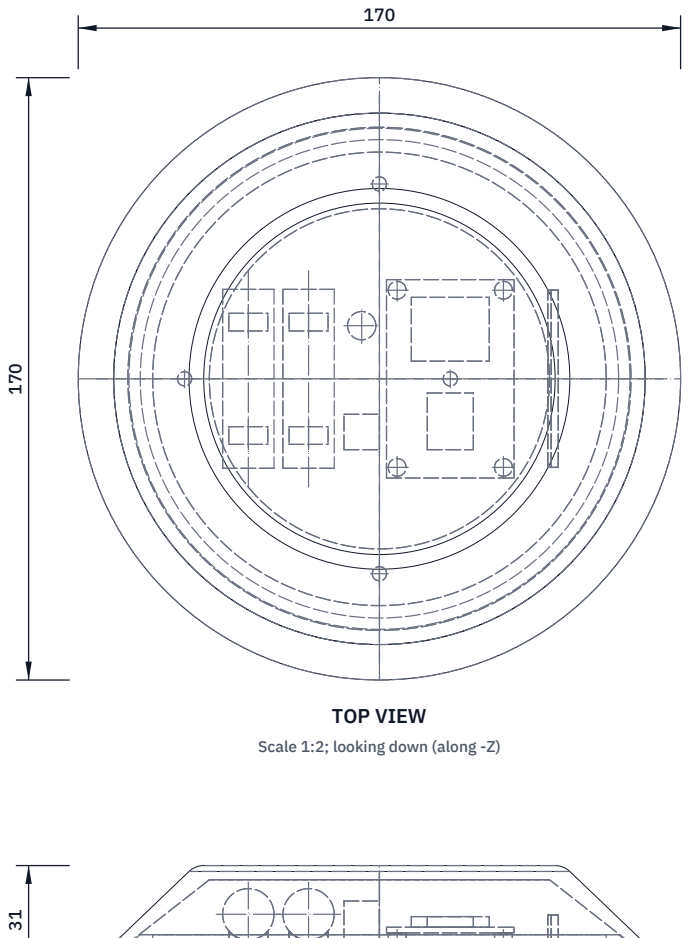
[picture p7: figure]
TOP VIEW; Scale 1:2; looking down (along -Z)

FRONT VIEW
Scale 1:2; looking at the front (along +Y)

RIGHT VIEW
Scale 1:2; looking at the right side (along -X)

ISOMETRIC VIEW
Not to scale; seen from the front right and above, about 30 deg elevation
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

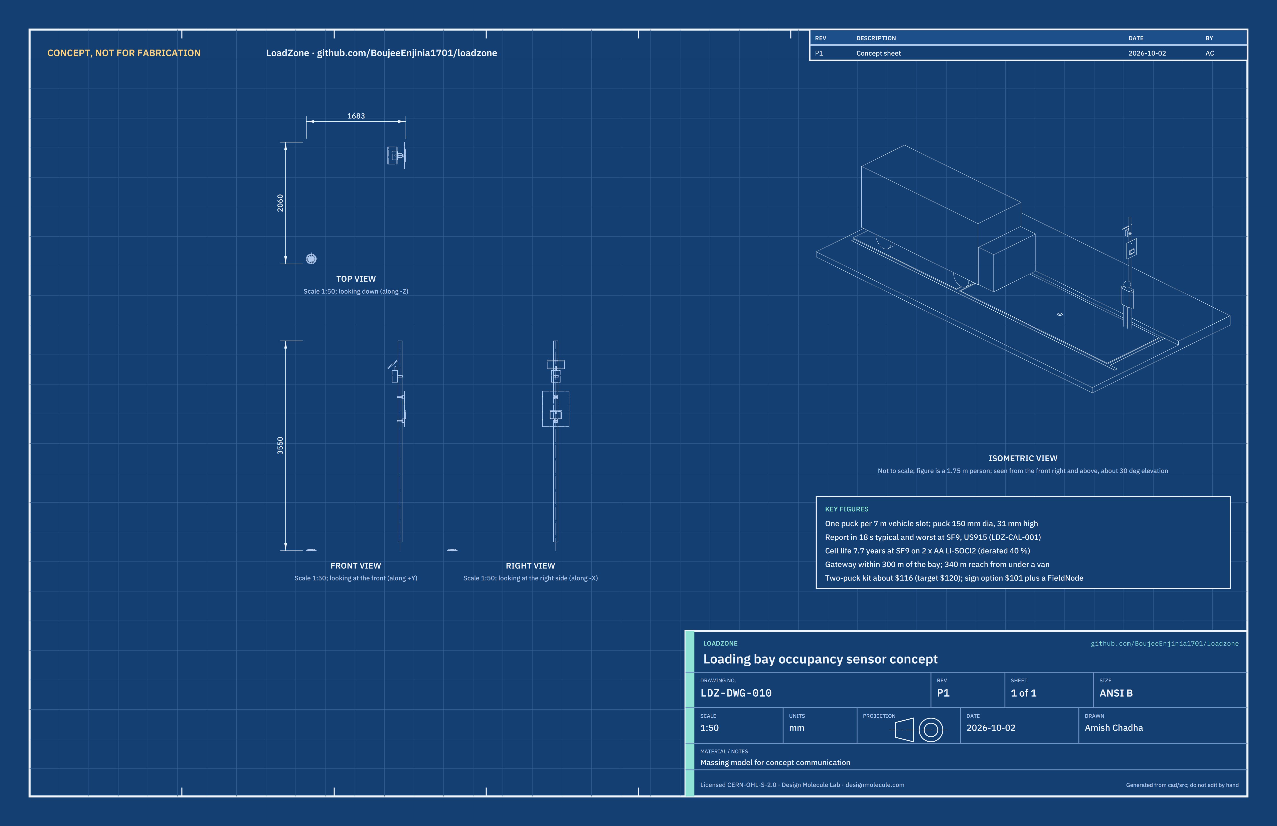
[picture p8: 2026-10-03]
media/concept-blueprint.png

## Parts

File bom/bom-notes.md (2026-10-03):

# BOM notes

Costs are indicative USD prices at quantity 1 for a concept estimate, not quotes. Every line is priced, with a supplier or supplier type. Totals are checked by `docs/04-calcs/sizing.py` (LDZ-CAL-001, section 10).

- Items 1 to 7 (per puck, quantity 2) and item 12 are the two-slot bay kit. Value-engineering target: USD 120 (`budget_usd`, a hypothetical control target, not a limit). Estimated cost of the constructable design: USD 116.00 (USD 4.00 under the target). One puck costs USD 54.00.
- Under LDZ-DDR-001 D6 (decided by Amish, 2026-09-25: go with recommendation; LDZ-DDR-002) the target covers the two-puck kit only. `budget_usd` stays 120.
- Items 8 to 10 are the sign option: USD 101.00, costed separately from the kit.
- Item 11, the host FieldNode, is priced once in the FieldNode BOM ($139.50 base node, FND-CAL-001) and shown here for reference; it is outside the two-puck kit cost. A bay with the sign costs USD 356.50.
- Item 5 changed at TRL 3 ($12.00 to $14.00): one Schottky diode per cell and an 85 °C hybrid pulse capacitor (LDZ-CAL-001, section 3). Decided by Amish, 2026-09-25: go with recommendation (LDZ-DDR-002, O6).
- Line numbers match the callouts in `media/exploded.png`.
- Item 7 is now two-part road-marker epoxy rather than a bitumen pad (LDZ-DDR-002, O3); the indicative price is unchanged at $4.00 per puck.
- A LoRaWAN gateway (TwinKit or an existing network) is not included; one is needed within 300 m of each bay (R4 as restated). The sign option needs a private network server for its downlinks (LDZ-DDR-002, O5).
- Design for construction (LDZ-DDR-003, 2026-10-01): item 6 is now a printed base tray with a locating ring, cradles, standoffs, an antenna rib and fill and vent holes (price unchanged); item 3 names the prototyping board and programming pads; item 9 names the enclosure, screws and gland; item 10 is now an aluminium channel bracket with a band clamp and bolts (USD 7.00, was USD 5.00); item 12 adds sealant, M2 screws and mould release (USD 8.00, was USD 6.00).
- Item 13 is one-off tooling for casting domes (printed mould master and core plug, silicone mould rubber), USD 35.00; it is not part of the per-kit cost.

Decided by Amish on 2026-10-02 (LDZ-DEC-001): the base tray is printed ASA sanded with 80 grit (item 4); the sign face (line 8) keeps a placeholder legend until the trial city is chosen and is then drawn to that city's sign rules (item 6); the potting (line 6) need not be a clear grade unless it costs no more (item 9); US915 is the default band, which sets the antenna band in line 4 (item 2). Carried out on 2026-10-02: line 4 is now a 915 MHz antenna (price unchanged at USD 3.00, indicative, same class as the 868 MHz part); line 11 now shows the FieldNode base node at USD 139.50 (FND-CAL-001), up from USD 126.00, which moves the bay with the sign from USD 343.00 to USD 356.50 and leaves the two-puck kit at USD 116.00. Puck mass is unchanged at 451 g without the pad.

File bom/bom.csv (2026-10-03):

item | qty | spec | supplier | unit_cost_usd | make_buy | notes
1 Puck dome | 2 | Rigid cast polyurethane, high-visibility yellow, UV stabilized; 150 mm base, 104 mm crown, 22 mm high, 4 mm wall, 6 mm crown radius; cast in a silicone mould with a printed core plug (line 13) | Resin supplier (casting polyurethane) plus local make | 5.00 | make | Indicative material cost at about 90 g of resin; cast polyurethane dome decided (LDZ-DDR-001 D5, LDZ-DDR-002); casting method LDZ-DDR-003
2 Magnetometer breakout | 2 | 3-axis 16-bit magnetometer, LIS2MDL class, I2C, 22 x 18 mm breakout | Electronics distributor (breakout makers such as Adafruit or SparkFun class) | 8.00 | buy | Indicative price
3 Controller and LoRa radio | 2 | STM32WL-class LoRaWAN module (RAK3172 or Wio-E5 class) with 2 MB SPI flash, one Schottky diode per cell, inline fuse and programming pads, on a 36 x 56 mm piece of prototyping board; FieldNode core | Electronics distributor | 14.00 | buy | Indicative price; same module family as FieldNode (FND-DDR-001 D2); prototyping board stands in for a carrier PCB, which is TRL 4 work
4 Internal antenna | 2 | Flexible PCB antenna, 915 MHz (US915 default band), adhesive backed, u.FL lead; about -2 dBi assumed once potted | Electronics distributor | 3.00 | buy | Indicative price at quantity 1 for a 915 MHz adhesive flexible antenna | the same class and price as the 868 MHz part; band decided as US915 by default (LDZ-DEC-001 item 2); confirm the part rating and u.FL lead when bought
5 Cell set | 2 | Two AA-size Li-SOCl2 bobbin cells (ER14505 class, 2.6 Ah each) in parallel through one Schottky diode each; 85 C hybrid pulse capacitor (at least 31 mF equivalent at SF9); inline fuse | Battery distributor (primary lithium specialist) | 14.00 | buy | Indicative price per puck; diodes and 85 C capacitor confirmed (LDZ-DDR-002, O6)
6 Puck base and potting | 2 | Printed ASA base tray: 150 mm disc 6 mm thick with a tapered locating spigot, two cradles per cell, four board standoffs, an antenna rib, an 8 mm fill hole and four 4 mm vents; about 175 cm3 semi-rigid polyurethane potting fills the dome | Resin supplier plus local make | 6.00 | make | Indicative material cost; tray features added for construction (LDZ-DDR-003)
7 Road-marker epoxy bed | 2 | Two-part road-marker epoxy for raised pavement markers, about 70 cm3 per puck as a 170 mm bed; surface cleaned and dry | Road-marking supplier | 4.00 | buy | Indicative price; epoxy chosen over a bitumen pad (LDZ-DDR-002); bond checked in LDZ-CAL-001 section 7
8 Sign face (option) | 1 | Aluminium composite panel 450 x 600 x 3 mm with printed Loading zone legend and display cut-out | Local sign maker | 22.00 | buy | Indicative price; sign option outside the $120 budget (LDZ-DDR-001 D6)
9 E-paper display and housing (option) | 1 | 7.5 in e-paper panel (800 x 480, 163 x 98 mm active) with driver board; bought polycarbonate enclosure with a clear lid, about 200 x 140 x 24 mm, four M4 x 12 pan-head screws with sealing washers and nuts and an M20 cable gland | Electronics distributor plus local make | 65.00 | buy | Indicative price; sign option outside the $120 budget
10 Sign pole brackets (option) | 2 | Aluminium U-channel 50 x 40 x 3 mm, 6063 class, cut 60 mm long, with a 12 mm stainless worm-drive band clamp for 60 to 90 mm poles and two M6 x 16 stainless button-head bolts with nyloc nuts | Hardware shop | 7.00 | buy | Indicative price; made bracket with a bought band clamp replaces the solid ring clamp of the concept (LDZ-DDR-003); sign option outside the two-puck kit
11 Host FieldNode (option) | 1 | Standard FieldNode core: 6 W panel, LiFePO4 cell, LoRaWAN class C, pole mount; see the FieldNode repo | FieldNode build (FND-CAL-001) | 139.50 | make | Priced once in the FieldNode BOM ($139.50 base node); shown for the sign option and excluded from the two-puck kit cost
12 Hardware and consumables | 1 | Wire, heat shrink, M2 x 5 self-tapping screws, polyurethane sealant for the rim seam, mould release, conformal coat, cleaning solvent | Hardware shop | 8.00 | buy | Indicative price; sealant, screws and mould release added for construction (LDZ-DDR-003); no exploded-view callout
13 Dome casting tooling (one-off) | 1 | Printed mould master (dome shape, plate and box wall in one print) and printed core plug, PETG, about 450 g in all; about 1 kg addition-cure silicone mould rubber | Filament and mould-making supplier, local make | 35.00 | make | Indicative price; one-off tooling for casting domes, not part of the per-kit cost (LDZ-DDR-003)

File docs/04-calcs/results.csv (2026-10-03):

id | value | target | status
R1 | Model: van 10.0 uT, high-chassis truck 7.7 uT, small car at slot end 10.5 uT, next lane 0.46 uT against a 3 uT threshold | 97 % of slot states correct over a day | At risk (not verifiable at TRL 3)
R2 | typical 17.7 s; worst 18.2 s at SF9, 18.4 s at SF10; no duty-cycle wait in US915 | 60 s or less | Met on paper
R3 | 7.7 years at SF9 (9.6 at SF7, 6.2 at SF10) with 40 % derating | 5 years or more at 100 changes a day plus hourly heartbeats | Met on paper
R4 | SF9 NLOS range 342 m with a van over and 10 dB fade margin; margin at 1 km -6.4 dB NLOS, 2.6 dB LOS | Gateway within 300 m in a street canyon with a van parked over the puck | Met on paper
R5 | 7.7 s/day at SF7, 14.0 at SF8, 25.5 at SF9, 46.0 at SF10 (124 uplinks; SF11 and SF12 are not offered in US915) | 30 s/day or less | At risk (met at SF7 to SF9; not met at SF10)
R6 | crown 7.4 MPa static, factor 5.4 on PU and 2.0 on potting; bond shear 1.51 MPa, factor 0.66 at 20 C, 0.13 at 50 C | 49 kN wheel (64 kN dynamic) crossing the puck while maneuvering, no cracking or debonding; parked wheels straddle it | At risk (debond under braking; epoxy bond)
R7 | 31 mm high, 150 mm diameter, 6 mm crown radius, yellow dome | 35 mm or less, rounded edges, high visibility | Met on paper
R8 | Cells -55 to +85 C, magnetometer and module -40 to +85 C class; pulse capacitor must be an 85 C hybrid type; fully potted | IP68; -25 to +70 C road surface; salt, oil, fuel | Met by design (sealing not verifiable at TRL 3)
R9 | Magnetometer only; 11-byte payload of state, timer, confidence, voltage, temperature | No images, audio or identifiers | Met by design
R10 | park_start, park_end, scheduled_report, comms_lost and comms_restored map onto CDS Events; occupancy and dwell onto Metrics | Open API mapping onto CDS Events and Metrics | Met by design
R11 | about 28 m by day at full contrast (78 mm digits); unlit at night, as restated | 25 m by day (daylight only, DDR-002) | Met on paper
R12 | 0.42 Wh/day drawn (17.7 mW) against 2.40 Wh/day (100 mW) | Within the host FieldNode allowance | Met on paper (private network only: 200 downlinks/day)
R13 | $116.00 for two pucks, $4.00 under the value-engineering target; sign option $101.00 plus FieldNode $139.50, costed separately (D6) | Two-puck kit: value-engineering target $120 | Met on paper (under the target)
R14 | Bonded pad, no road cutting; time depends on the adhesive | 15 min per puck, two-person crew | Not verifiable at TRL 3
R15 | No external fasteners; bonded; removal flagged by a field and orientation step | No screws; removal reported | Met by design

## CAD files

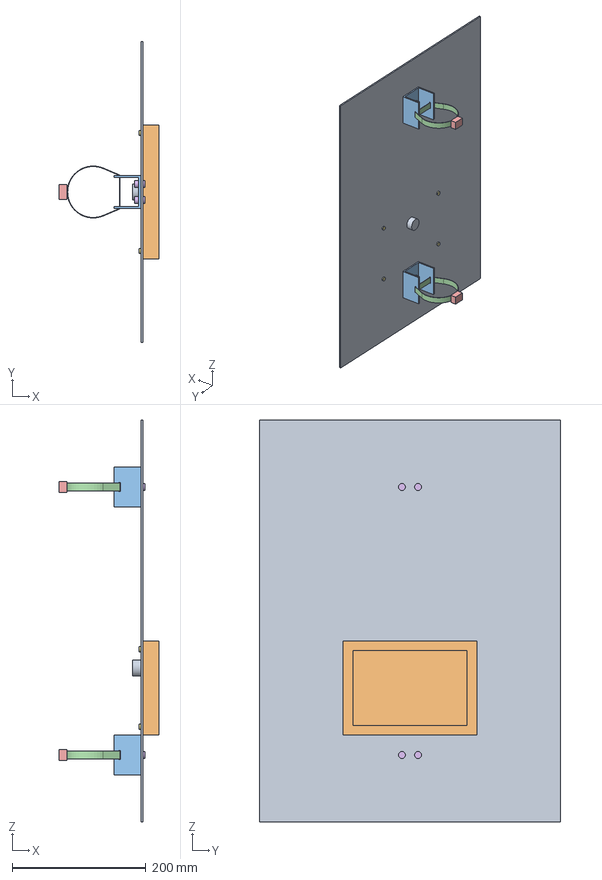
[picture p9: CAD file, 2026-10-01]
cad/step/loadzone-sign-option.step
148.8 x 450.0 x 600.0 mm

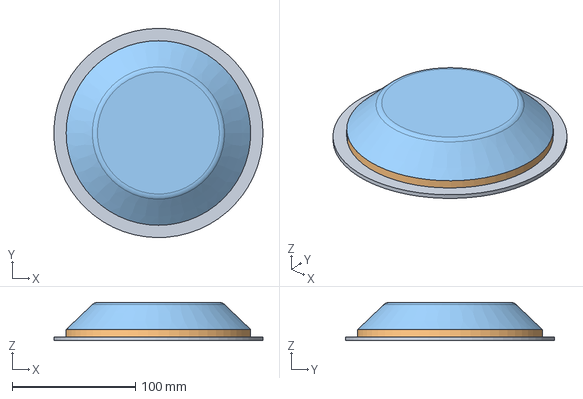
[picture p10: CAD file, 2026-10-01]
cad/step/loadzone-puck.step
169.9 x 169.9 x 31.0 mm

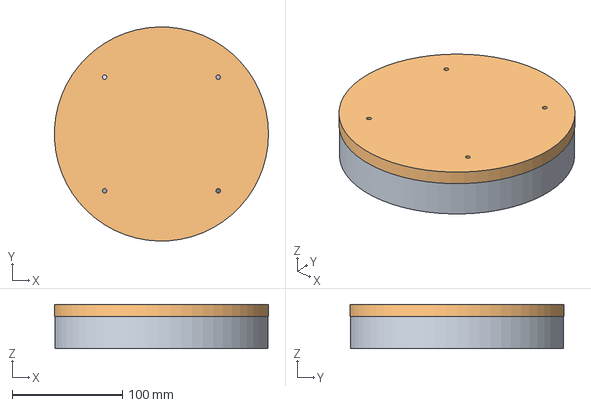
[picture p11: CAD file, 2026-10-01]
cad/step/loadzone-dome-tooling.step
194.5 x 194.5 x 40.0 mm

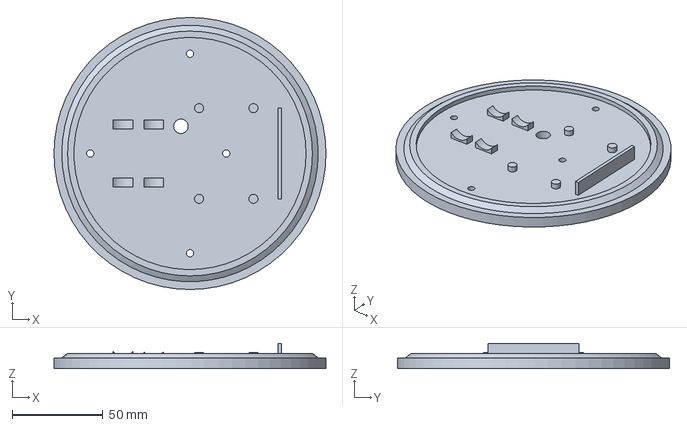
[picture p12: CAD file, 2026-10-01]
cad/step/loadzone-base-tray.step
150.0 x 150.0 x 14.0 mm

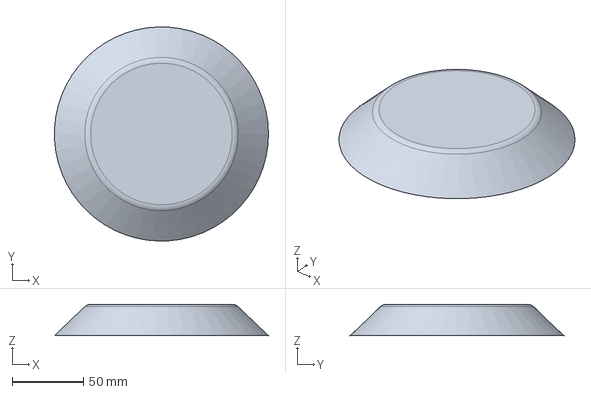
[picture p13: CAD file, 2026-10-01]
cad/step/loadzone-dome.step
149.9 x 149.9 x 22.0 mm

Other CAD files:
cad/stl/loadzone-base-tray.stl
cad/stl/loadzone-dome-tooling.stl
cad/stl/loadzone-dome.stl
cad/stl/loadzone-puck.stl
cad/stl/loadzone-sign-option.stl

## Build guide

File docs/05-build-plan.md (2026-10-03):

---
doc_id: LDZ-BLD-001
title: LoadZone prototype build plan
project: LoadZone
doc_type: Build plan
version: "0.3"
status: Draft
date: '2026-10-02'
author: Amish Chadha
license: CERN-OHL-S-2.0
revisions:
  - version: "0.1"
    date: '2026-10-01'
    author: Amish Chadha
    change: First build plan, with pictures by component and step; design made constructable (LDZ-DDR-003)
  - version: "0.2"
    date: '2026-10-02'
    author: Amish Chadha
    change: 'Sign legend: placeholder for the prototype; drawn to the city''s rules and approved by its traffic engineer before street mounting (LDZ-DEC-001, item 6)'
  - version: "0.3"
    date: '2026-10-02'
    author: Amish Chadha
    change: 'Antenna named for 915 MHz (US915 default band); first-check airtime figure for the 11-byte payload'
---

# LoadZone prototype build plan

**Plan, not yet built.** How to build the first proof-of-concept prototype, component by component. Building and testing to it is TRL 4 work. Decisions still to be made are kept in the design decisions register ([docs/06-design-decisions.md](06-design-decisions.md)), not here.

## 1. What you are building

Figure 1. Every component, pulled apart and numbered in build order

*Figure 1. Every component pulled apart and numbered in build order. The puck (1 to 7) is drawn at twice the scale of the sign option (8 to 11).*

The prototype is the two-slot bay kit: two LoadZone pucks, each bonded to a test slab in the workshop, and, as an option, one "Loading zone" sign with an e-paper display on a short length of pole. Each puck is a yellow polyurethane dome, cast in a home-made mould, sitting on a printed base tray that carries two primary lithium cells, a small radio board with a magnetometer, and a flexible antenna; the whole inside is then filled with potting resin through a hole in the tray, so the puck is solid and sealed for life. Figure 1 shows the 11 components in the order you make or fit them. Made in the workshop: the dome (with its printed mould master, silicone mould and printed core plug), the base tray, the radio board, the potting, and the two sign brackets; the sign face and the display housing are bought and drilled; everything else is bought and fitted. The work is 3D printing, casting polyurethane and silicone, soldering bought modules, pouring potting, and sawing and drilling aluminium channel and sign panel. The two-puck kit costs about USD 116 in parts from the bill of materials; the sign option is costed separately and runs from a host FieldNode built to the FieldNode build plan.

> **Safety:** Each puck holds two lithium thionyl chloride cells, which must never be charged, shorted, heated, crushed or opened: they can vent toxic, corrosive gas and burn. Polyurethane casting resins and potting contain isocyanates, and road-marker epoxy can sensitize skin: cast, pot and bond only with ventilation, gloves, eye protection and, for isocyanates, a suitable respirator. Bonding a puck to a real road is outside this plan and needs a permit, a trained crew and traffic management. Cut aluminium edges are sharp: deburr them and wear gloves.

## 2. What changed to make it buildable

The concept showed what LoadZone does; some of its parts could not be made, fitted or potted as drawn. Each change below keeps what the puck and the sign do, and all of them are recorded in decision record LDZ-DDR-003, open for Amish's review.

*Table 1. Changes from the concept.*

| Component | The concept had | The buildable design has | Why |
| --- | --- | --- | --- |
| Base | A flat disc with no joint to the dome and no way to pour the potting | A printed tray with a tapered locating ring, an 8 mm fill hole and four 4 mm vents; the dome's seam is sealed; the puck is potted upside down (Figures 7, 8 and 11) | The dome locates and seals, and air leaves through the vents as the potting rises |
| Parts inside the puck | Cells, board and antenna floating in the cavity | Cell cradles, board standoffs and an antenna rib printed on the tray (Figure 9) | Every part is held while it is wired, tested and potted |
| Cells and antenna | Cells 1.2 mm and antenna 1.9 mm from the dome wall | Cells moved 3 mm and the antenna 2 mm toward the centre: 2.5 mm and 3.8 mm clear | Room for the solder tabs and for the potting to flow |
| Dome | "A printed silicone mould", with no core | A printed master, a silicone mould cast in it and a printed core plug (Figures 2 to 5) | A dome with a cavity needs both an outer mould and a core |
| Radio board | No way to program or test it once potted | Programming pads, with programming and a bench test as a hold point before the dome goes on | The potted puck cannot be opened again |
| Sign mounting | Solid rings round the pole, arms only touching the sign | Aluminium channel brackets bolted to the sign, with stainless band clamps through slots in their flanges (Figures 13 to 15) | A closed ring cannot be fitted to a pole; a band clamp can |
| Display housing | A solid block on the sign with no fixing or cable path | A bought enclosure with a clear lid, screwed from behind the sign, with a cable gland through the sign face (Figure 19) | The housing is held and sealed and its cable runs behind the sign |

## 3. Making the components

Make and check each component before the step that needs it. Sizes are in millimetres. On the puck, "left" and "right" are as seen from above with the antenna rib on the right; positions are measured from the centre of the tray. On the sign, heights are measured up from the bottom edge of the sign face and sideways from its centre line. Workshop tolerance is 0.5 mm unless a step says otherwise; drawings do not carry tolerances before TRL 4.

### 3.1 Mould master

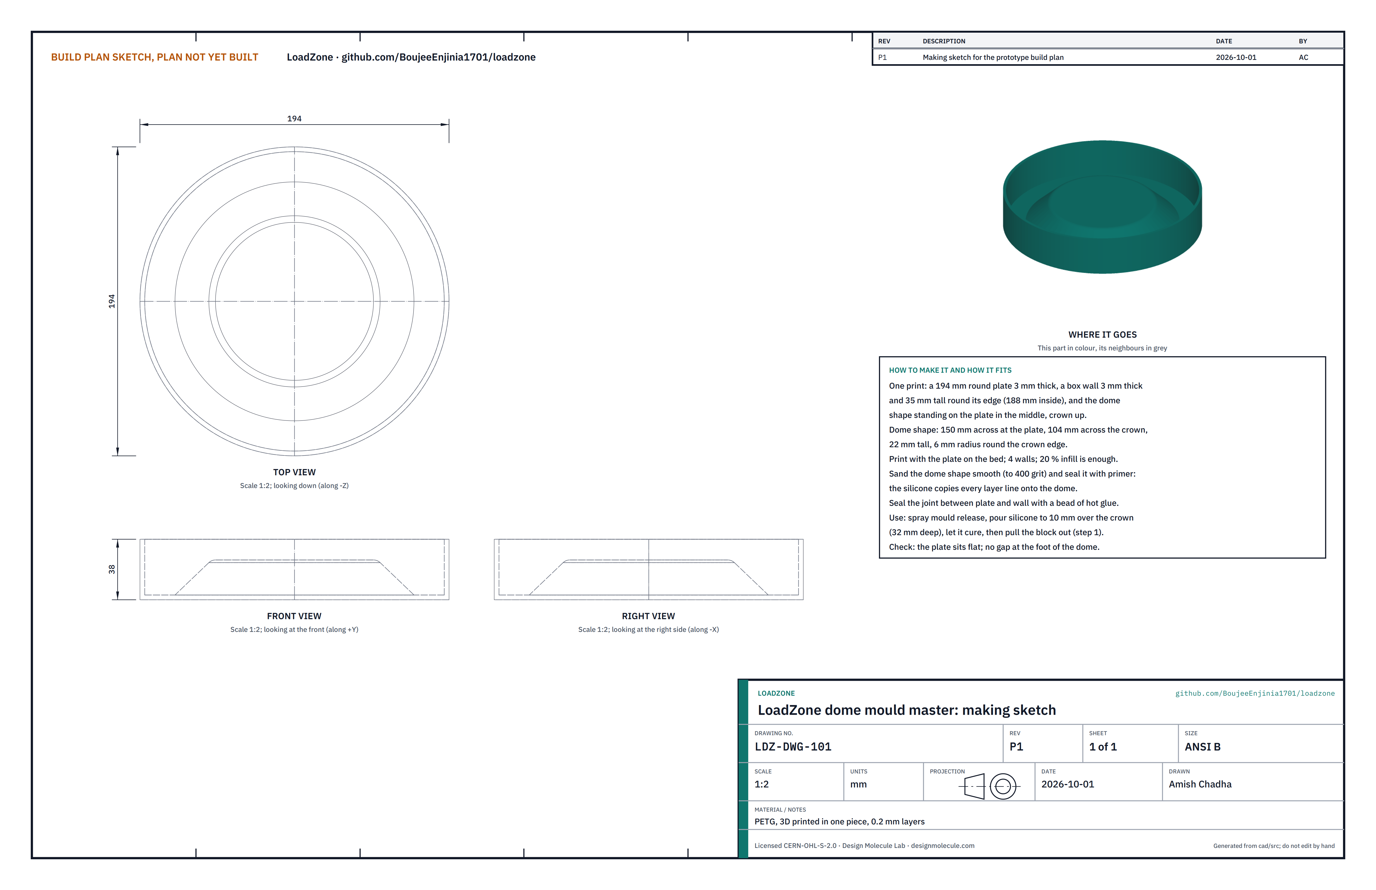
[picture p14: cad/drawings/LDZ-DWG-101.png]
Figure 2. Making sketch of the mould master


*Figure 2. Mould master making sketch (LDZ-DWG-101).*

**What it is and what it is made from.** A one-piece print that has the outside shape of the dome standing on a plate inside a round box; silicone is poured into it to make the mould. PETG, printed at 0.2 mm layers.

**How to make it.**

1. Print the plate (194 mm across, 3 mm thick) on the bed, with its box wall (3 mm thick, 35 mm tall, 188 mm inside) and the dome shape (150 mm across at the plate, 104 mm across the crown, 22 mm tall, 6 mm radius round the crown edge) in one piece. Four walls and 20 % infill are enough.
2. Sand the dome shape to 400 grit and seal it with a sanding primer; the silicone copies every layer line onto the dome.
3. Run a bead of hot glue round the inside foot of the box wall so silicone cannot leak through the print.

**How it fits the parts next to it.** The silicone fills the box to 10 mm over the crown (32 mm deep) and takes the dome's outside shape (step 1).

**Check before moving on.** The plate sits flat on a glass sheet; the dome shape has no gap at its foot.

### 3.2 Silicone mould

**What it is and what it is made from.** A block of addition-cure (platinum) silicone, 188 mm across and 32 mm tall, with the dome's outside shape as a cavity in one face. About 1 kg of mould rubber.

**How to make it.**

1. Spray the master with the silicone maker's release agent. Try a small patch of silicone on a scrap of the same primer first: some primers stop platinum silicone curing.
2. Mix the silicone by weight, degas it if you can, and pour it slowly into one corner of the box so it flows over the dome shape without trapping air. Fill to 10 mm over the crown.
3. Let it cure for the maker's full time, then pull the block out and turn it over: the cavity faces up (step 1, Figure 3).

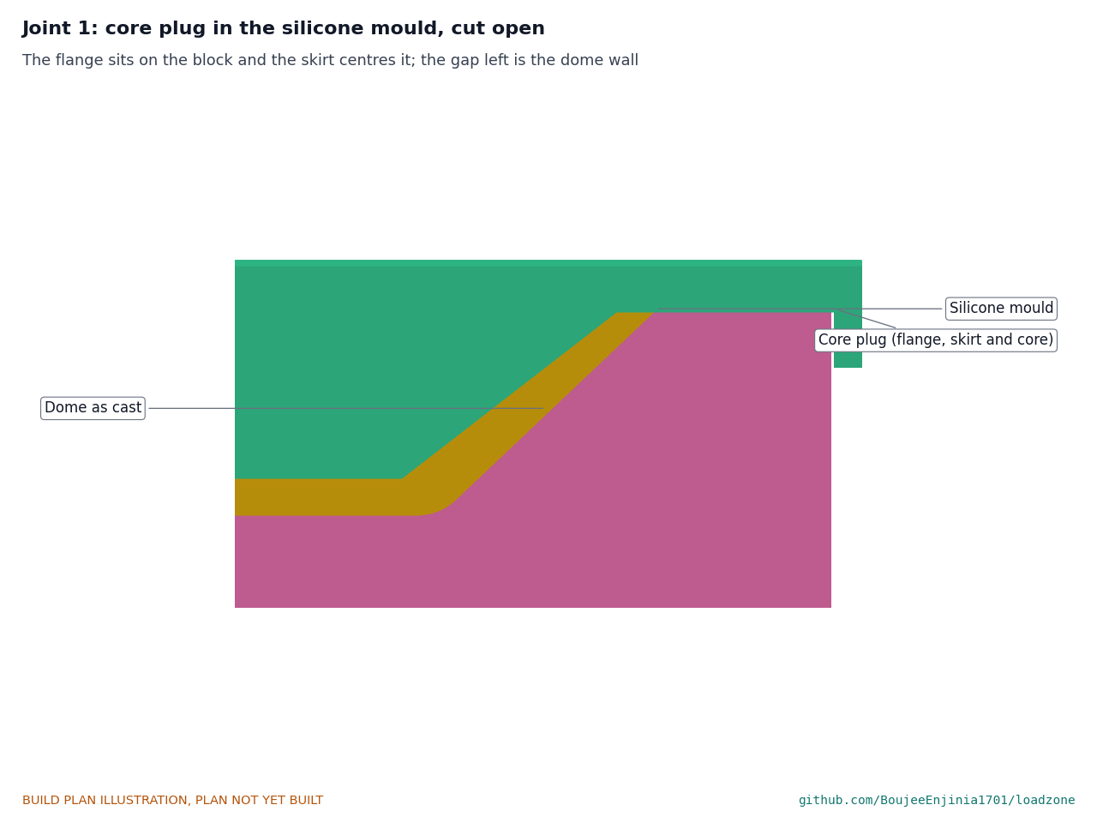
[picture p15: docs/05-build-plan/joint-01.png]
Figure 3. Joint 1: core plug in the silicone mould, cut open


*Figure 3. The core plug's flange sits on the top of the block and its skirt centres it; the gap between the core and the cavity is the dome.*

**How it fits the parts next to it.** The core plug sits on its top face (Figure 3).

**Check before moving on.** The cavity is smooth and free of bubbles; the top face is flat.

### 3.3 Core plug

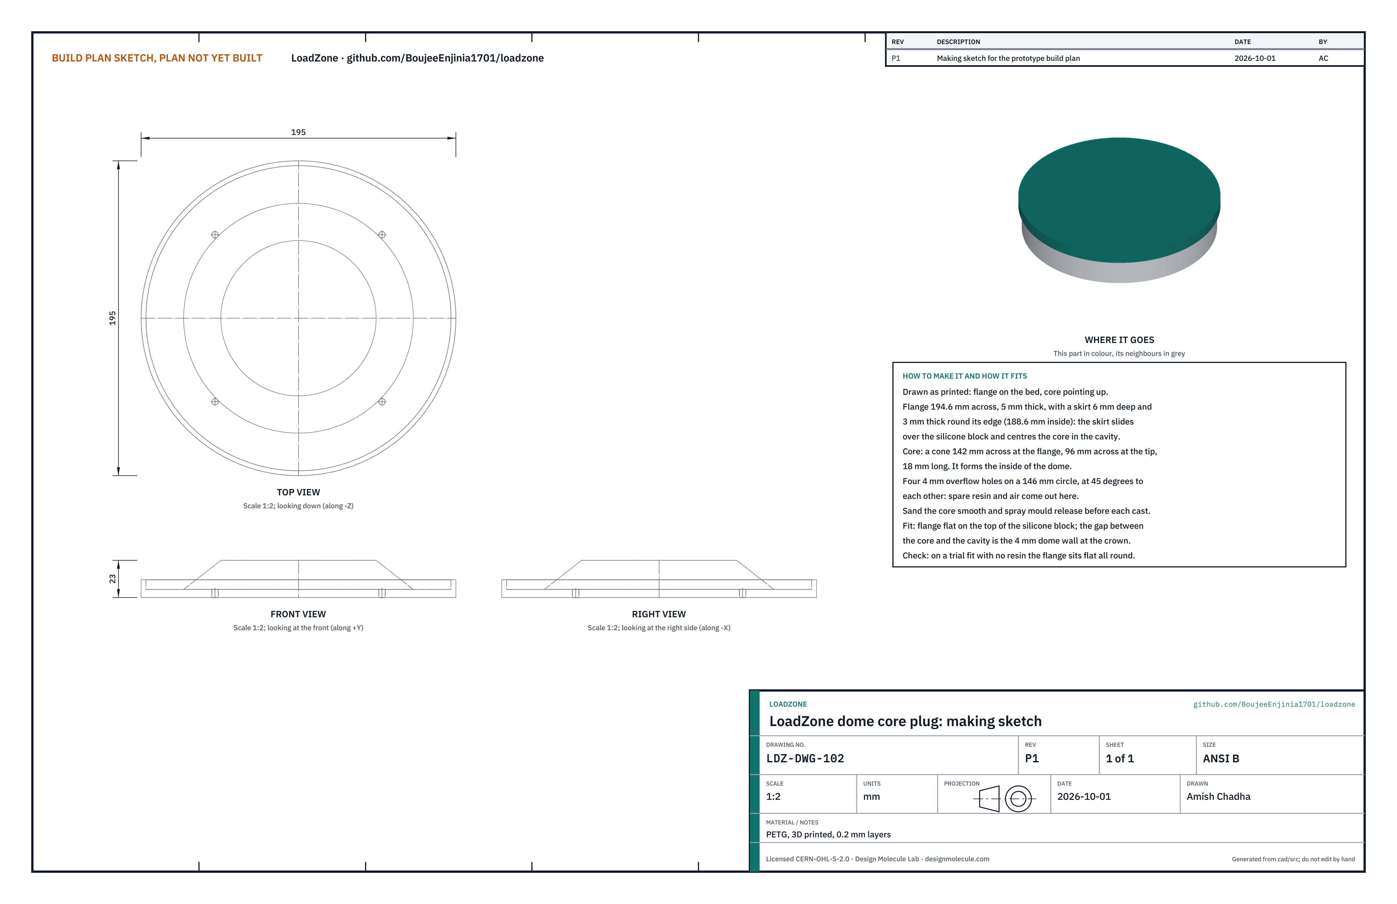
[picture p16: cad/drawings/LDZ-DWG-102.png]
Figure 4. Making sketch of the core plug


*Figure 4. Core plug making sketch (LDZ-DWG-102), drawn as printed.*

**What it is and what it is made from.** A printed lid for the mould whose cone forms the inside of the dome. PETG, printed flange down.

**How to make it.**

1. Print the flange (194.6 mm across, 5 mm thick) with its skirt (6 mm deep, 3 mm thick, 188.6 mm inside) round the edge and the cone (142 mm across at the flange, 96 mm across the tip, 18 mm long) in the middle.
2. Print or drill four 4 mm overflow holes through the flange on a 146 mm circle, at 90 degrees to each other.
3. Sand the cone smooth and seal it as in 3.1.

**How it fits the parts next to it.** The flange rests flat on the silicone block, the skirt slides over the block's outside with 0.3 mm to spare, and the cone hangs in the cavity with a 4 mm gap at the crown (Figure 3). The overflow holes sit over the rim of the dome, where spare resin and air come out.

**Check before moving on.** On a trial fit with no resin, the flange sits flat all round and the core does not touch the cavity anywhere.

### 3.4 Dome (make 2)

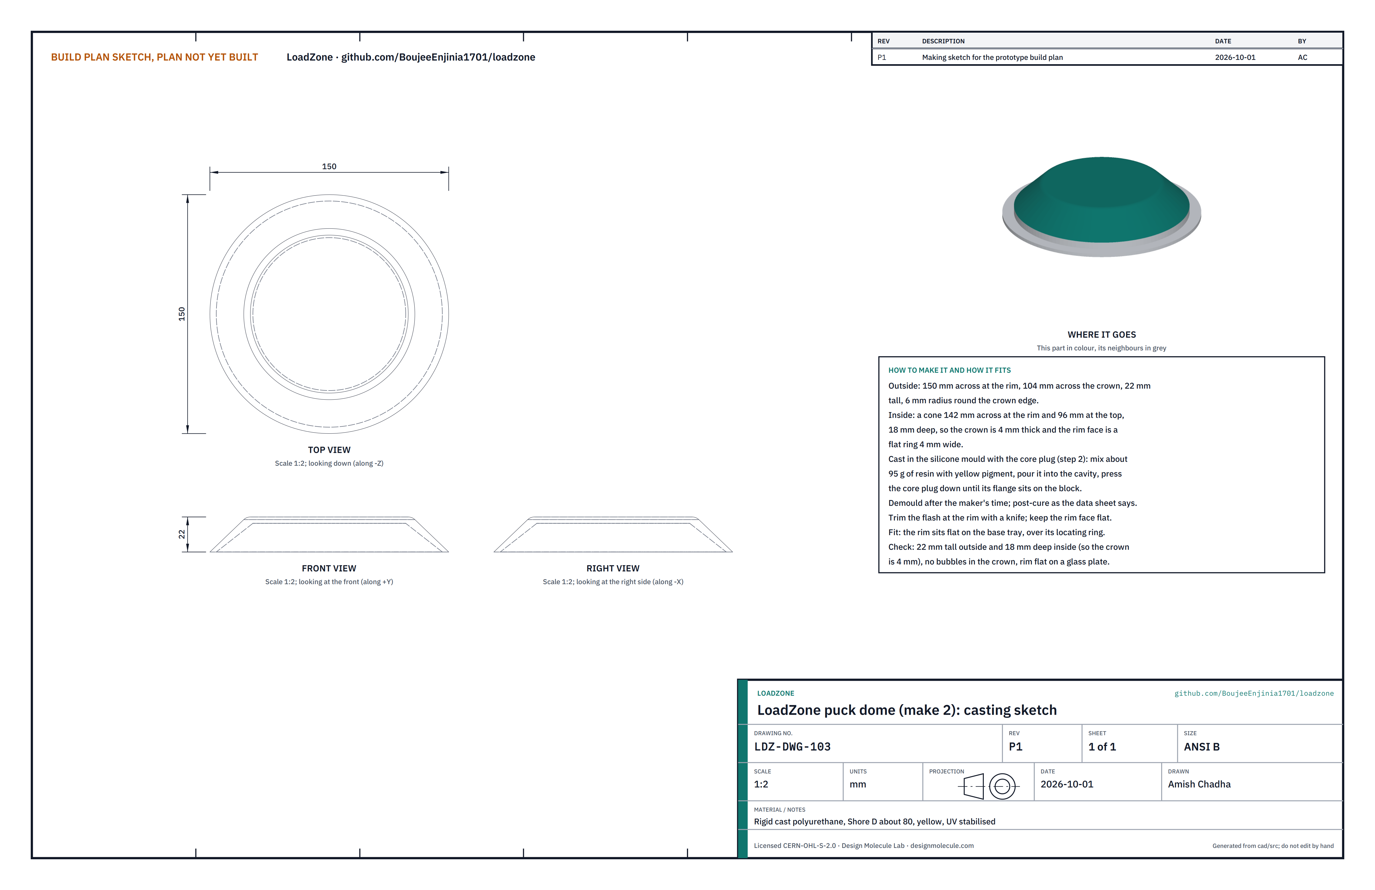
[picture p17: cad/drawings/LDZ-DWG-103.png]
Figure 5. Casting sketch of the dome


*Figure 5. Dome casting sketch (LDZ-DWG-103).*

**What it is and what it is made from.** The yellow dome that takes the wheel loads and keeps water out. Rigid casting polyurethane, about Shore D 80, with yellow pigment and a UV stabiliser.

**How to make it.**

1. Spray the cavity and the core with release agent and let it flash off.
2. Weigh out about 95 g of resin and hardener, add the pigment, and mix as the maker says. Degas if you can.
3. Pour the resin into the cavity, then press the core plug down slowly until its flange sits on the block all round (step 2). Spare resin rises through the overflow holes.
4. Leave it for the maker's demould time, lift off the core and flex the silicone to release the dome. Post-cure as the data sheet says.
5. Trim the flash at the rim with a sharp knife, keeping the rim face flat. Make the second dome the same way.

**How it fits the parts next to it.** The flat rim, 4 mm wide, sits on the base tray over its locating ring (Figure 8).

**Check before moving on.** The dome is 22 mm tall outside and 18 mm deep inside, so the crown is 4 mm thick; there are no bubbles in the crown; the rim lies flat on a glass sheet.

### 3.5 Base tray (make 2)

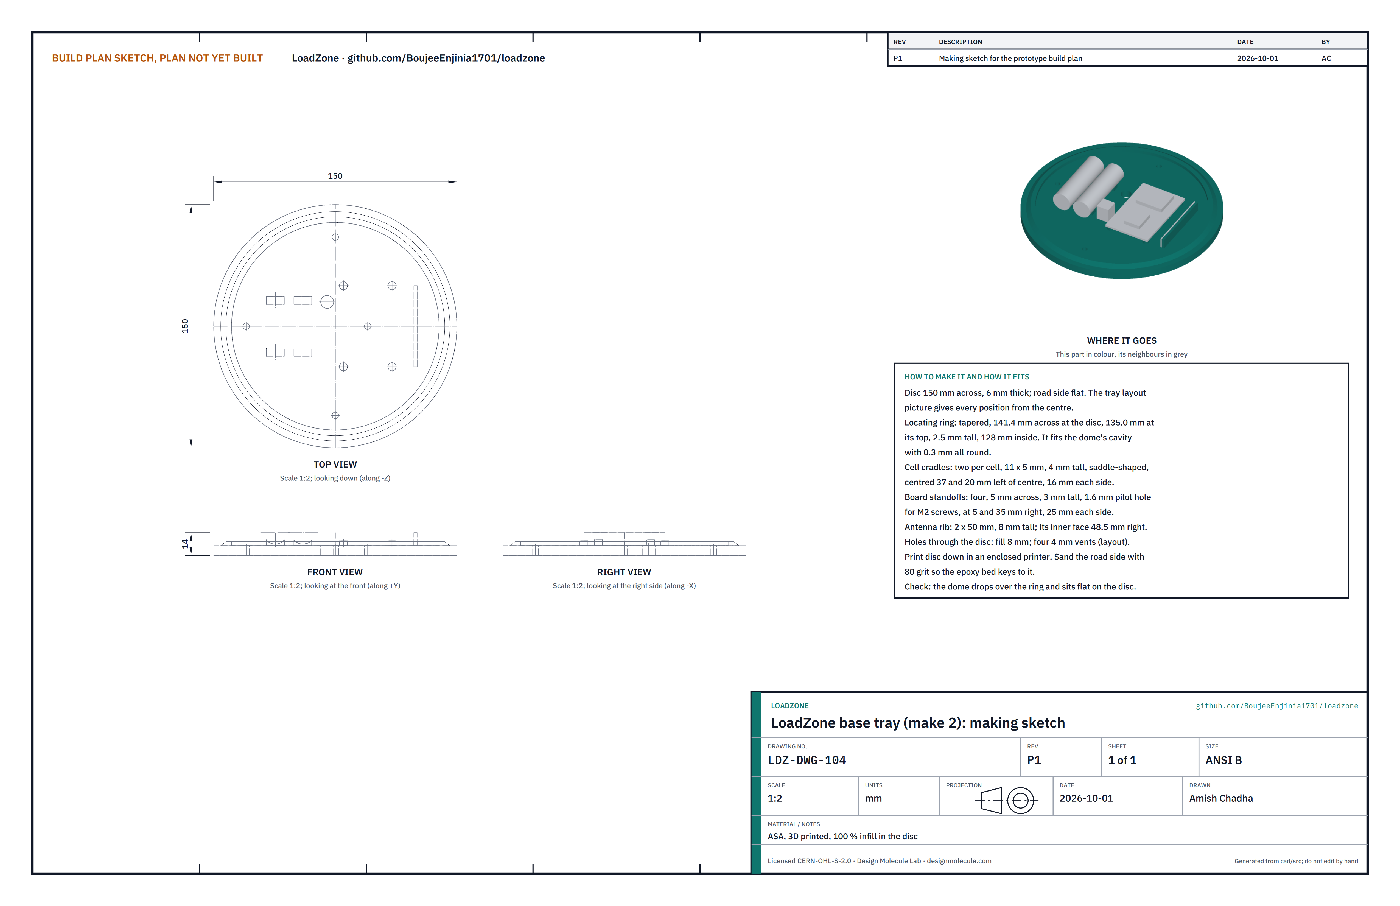
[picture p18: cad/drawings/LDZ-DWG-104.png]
Figure 6. Making sketch of the base tray


*Figure 6. Base tray making sketch (LDZ-DWG-104).*

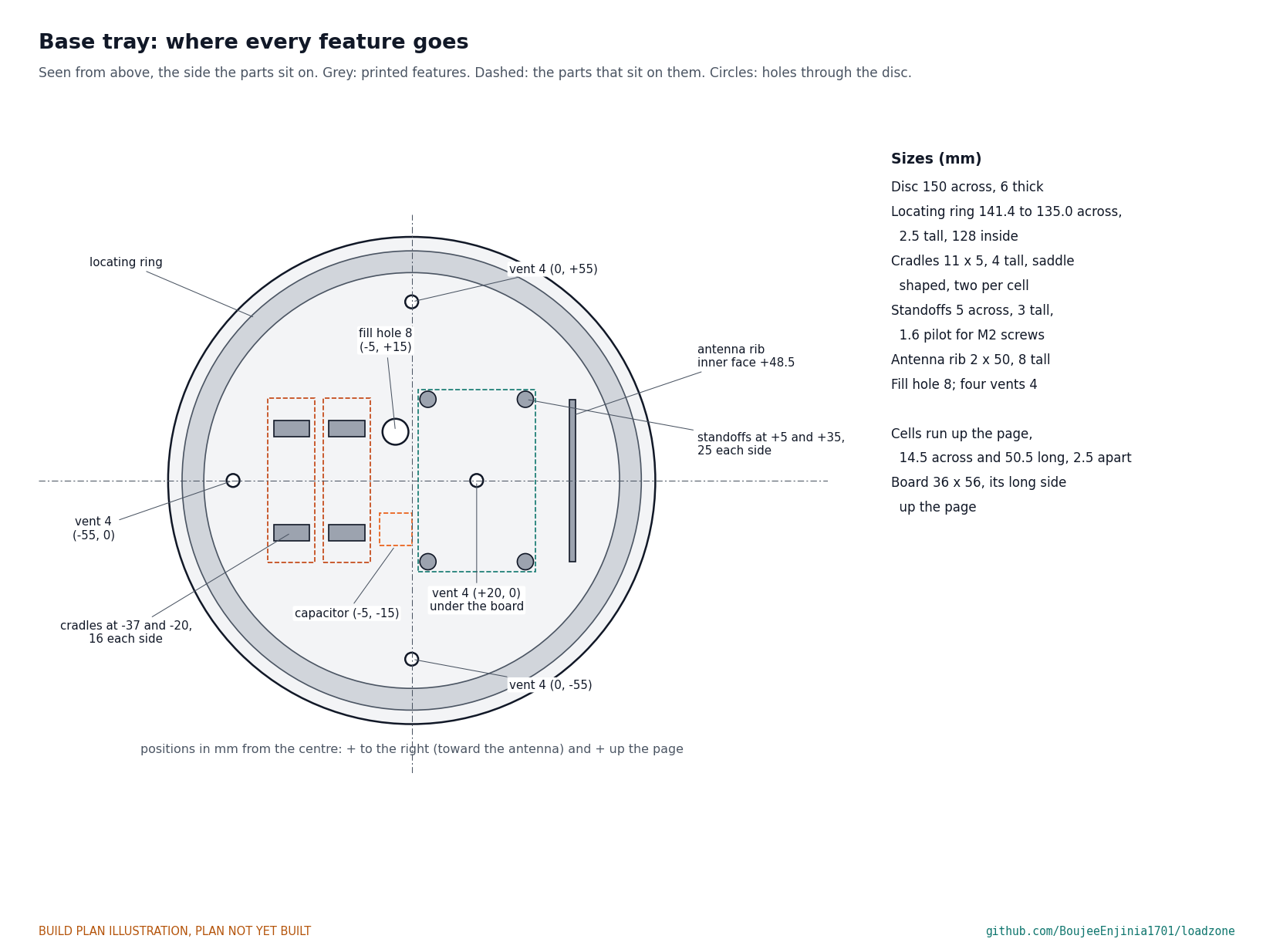
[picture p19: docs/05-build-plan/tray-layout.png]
Figure 7. Base tray feature positions


*Figure 7. Where every feature goes, seen from above, with the parts that sit on them dashed.*

**What it is and what it is made from.** The bottom of the puck: a disc that carries every part inside and closes the dome. ASA, printed in an enclosed printer, solid in the disc.

**How to make it.**

1. Print the disc (150 mm across, 6 mm thick) flat side down, with its features on top, as Figure 7 shows:
   - the locating ring, tapered, 141.4 mm across at the disc and 135.0 mm across its top, 2.5 mm tall, 128 mm inside;
   - two saddle-shaped cradles for each cell, 11 x 5 mm and 4 mm tall, centred 37 and 20 mm left of centre and 16 mm each side of it;
   - four board standoffs, 5 mm across and 3 mm tall with a 1.6 mm pilot hole, 5 and 35 mm right of centre and 25 mm each side;
   - the antenna rib, 2 x 50 mm and 8 mm tall, its inner face 48.5 mm right of centre;
   - the 8 mm fill hole, 5 mm left and 15 mm up from centre, and four 4 mm vents: one 20 mm right of centre (under the board), one 55 mm left, and two 55 mm up and down.
2. Sand the flat road side with 80 grit so the epoxy bed keys to it. Keep the holes clear.

**How it fits the parts next to it.** The dome drops over the locating ring with 0.3 mm all round and its rim sits flat on the disc:

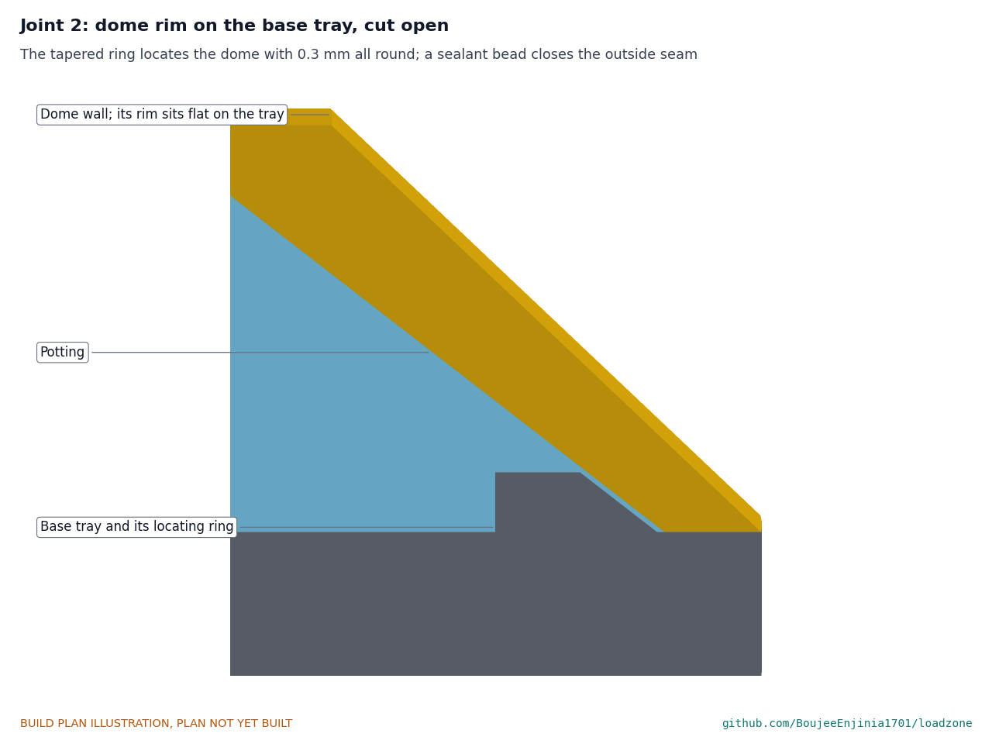
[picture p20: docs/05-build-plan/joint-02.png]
Figure 8. Joint 2: dome rim on the base tray, cut open


*Figure 8. The tapered ring centres the dome; the potting fills the inside up to the dome wall.*

**Check before moving on.** A dome drops over the ring and sits flat on the disc without rocking; a cell lies in its two cradles without rolling.

### 3.6 Electronics on the tray

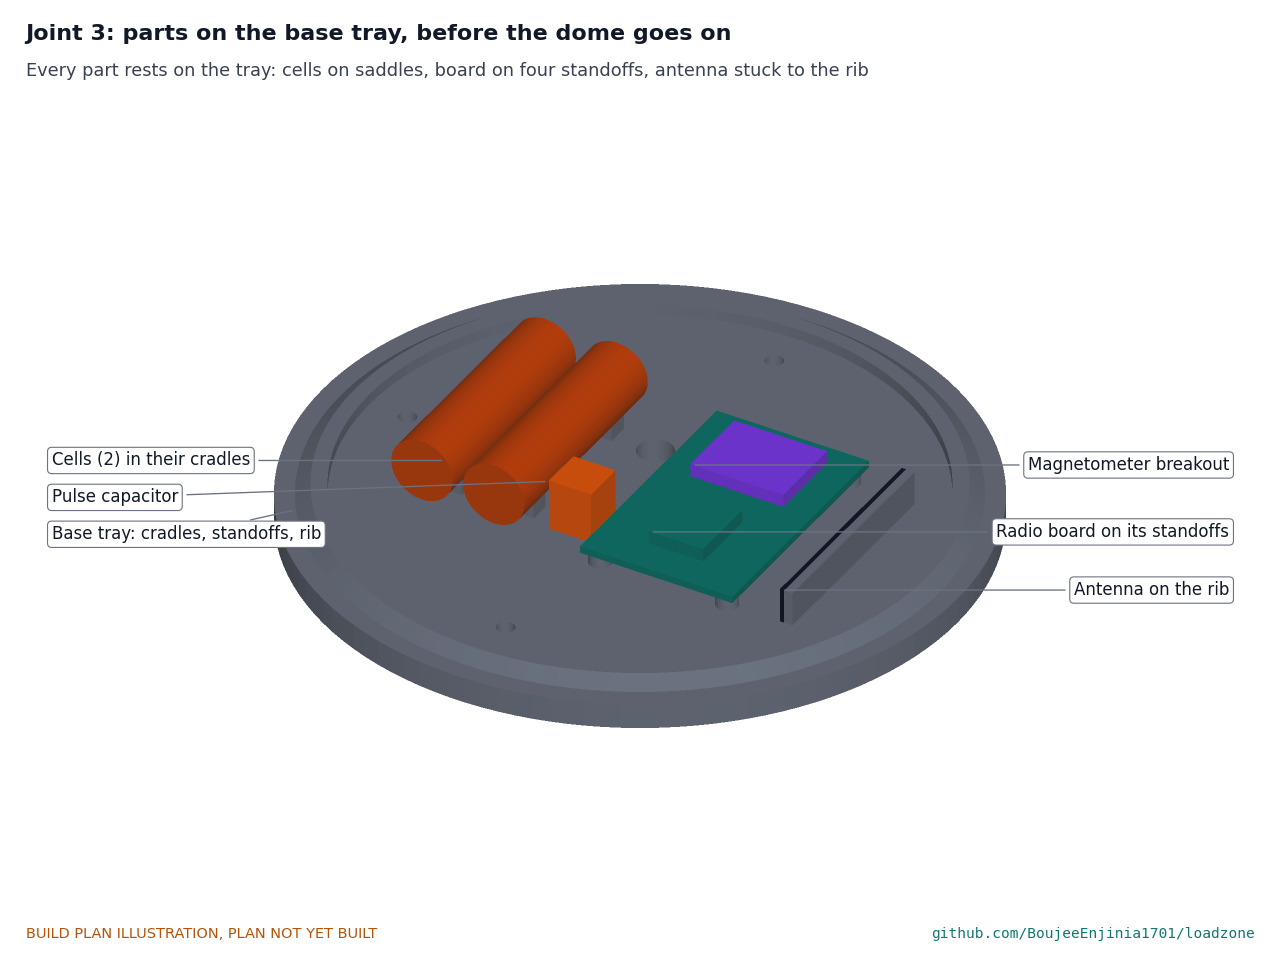
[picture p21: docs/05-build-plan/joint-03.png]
Figure 9. Joint 3: parts on the base tray


*Figure 9. Every part rests on the tray: cells on their saddles, the board on four standoffs, the antenna on the rib.*

**What it is and what it is made from.** The cells, pulse capacitor, radio board, magnetometer and antenna, all bought, wired together on the tray. The radio board is a 36 x 56 mm piece of prototyping board carrying the radio module, a 2 MB memory chip, one Schottky diode for each cell, a 0.5 A fuse and programming pads; the magnetometer breakout sits on top of it, flat, so its vertical sensing axis points up.

**How to make it.**

1. Build the radio board: solder the module, memory, diodes, fuse and pads to the prototyping board, and drill a 2.2 mm hole at each corner to match the standoffs (30 x 50 mm apart).
2. Fix the board to the four standoffs with M2 x 5 self-tapping screws. Stick the magnetometer breakout to the board with double-sided foam tape and wire it.
3. Stick the antenna to the inner face of the rib, its trace away from the board, and plug its lead into the module.
4. Stand the pulse capacitor in its place (5 mm left and 15 mm down from centre) with a dab of adhesive.
5. Wire the cells and capacitor as Figure 10 shows. Use cells with factory-welded solder tabs; never solder to the cell can. Lay each cell in its cradles with a dab of adhesive.

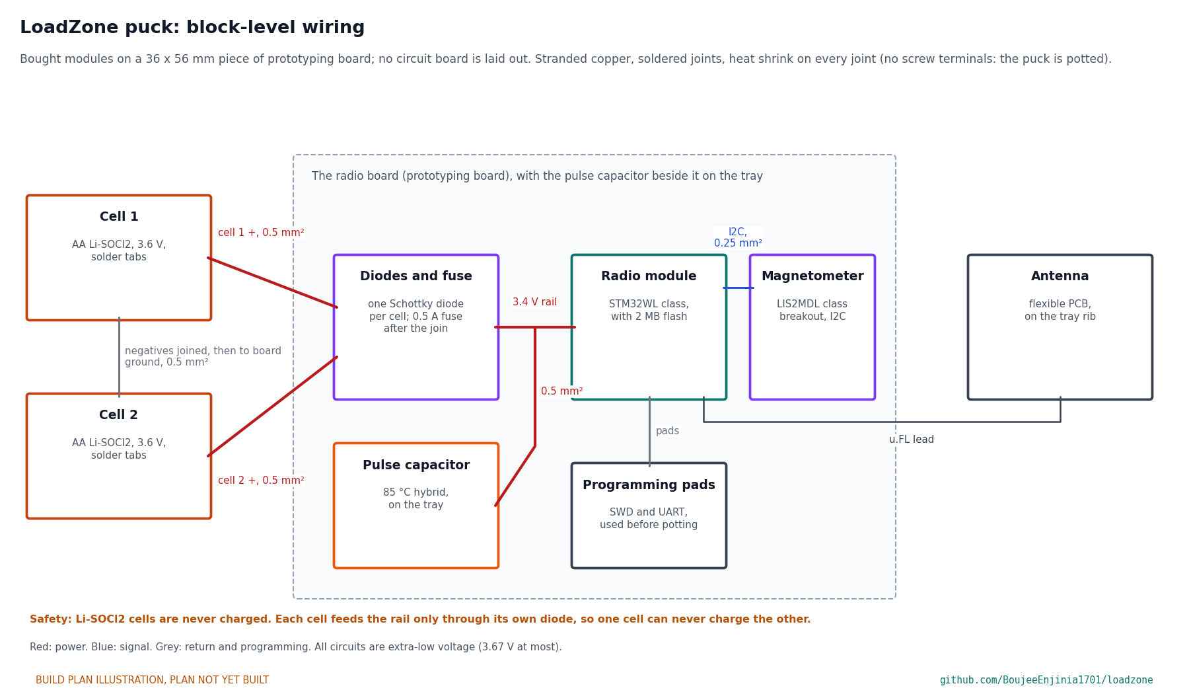
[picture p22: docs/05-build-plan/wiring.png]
Figure 10. Block-level wiring of the puck


*Figure 10. Block-level wiring with wire sizes. No circuit board is laid out at this stage; bought modules on prototyping board stand in for it.*

Wire it like this, with stranded copper, soldered joints and heat shrink on every joint:

1. Each cell's positive tab to its own Schottky diode on the board: 0.5 mm² (20 AWG). The two diodes join after their cathodes, then pass through the 0.5 A fuse to the supply rail.
2. Both negative tabs joined together and to the board's ground: 0.5 mm².
3. The pulse capacitor across the supply rail and ground, as close to the module as the leads allow: 0.5 mm².
4. The magnetometer to the module's I2C pins and to the supply rail: 0.25 mm² (24 AWG).
5. The antenna's u.FL lead to the module, routed away from the cell leads.
6. The programming pads to the module's SWD and UART pins.

**How it fits the parts next to it.** Every part stands on the tray and nothing touches the dome: the cells sit 2.5 mm inside the dome wall, the antenna 3.8 mm, and the board's top 10 mm below the dome. The board's 3 mm gap and the vent under it let potting flow under the board.

**Check before moving on.** This is the hold point of step 3: the board is programmed through its pads; a bench uplink reaches a gateway; with both cells fitted, the supply rail reads about 3.4 V; the sleep current is a few microamps (section 5). Then cut the programming wires off at the pads.

### 3.7 Potting

**What it is and what it is made from.** About 175 cm³ of semi-rigid polyurethane potting that fills every gap inside the dome, carries wheel loads from the crown to the tray, and seals the electronics. Choose a low-exotherm grade rated for electronics.

**How to make it.** Steps 4 and 5: dome on, seam sealed, puck upside down, potting poured through the fill hole until it shows at every vent, topped up, cured and scraped flush.

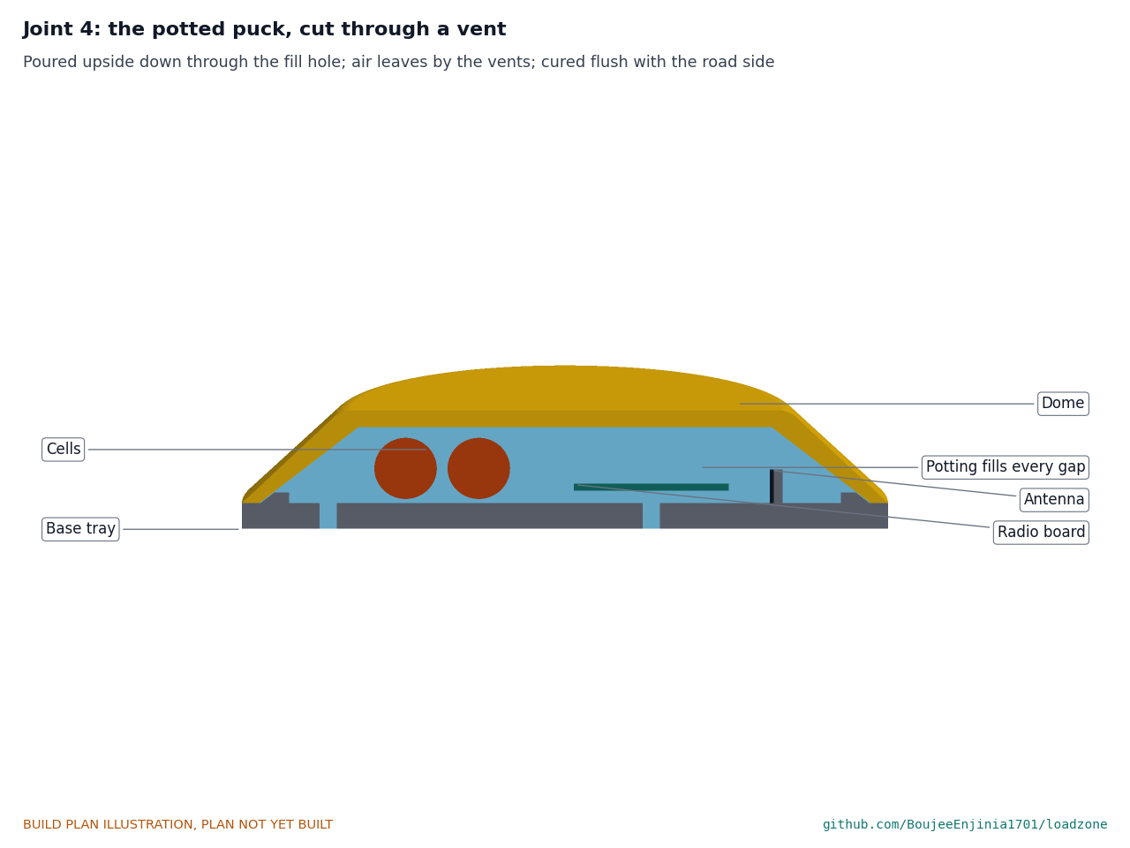
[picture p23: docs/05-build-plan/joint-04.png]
Figure 11. Joint 4: the potted puck, cut through a vent


*Figure 11. The potting fills the dome around the cells, board and antenna and fills the fill hole and vents flush with the road side.*

**How it fits the parts next to it.** It bonds to the inside of the dome, the tray and every part, and finishes flush with the road side of the tray.

**Check before moving on.** Resin stands in every vent; after cure, the road side is flat and a tap round the dome sounds the same everywhere (no hollow spots).

### 3.8 Epoxy bed and test slab

**What it is and what it is made from.** The bond between puck and road: a 3 mm bed of two-part road-marker epoxy, 170 mm across, on a test slab of asphalt or a concrete paver at least 300 mm square.

**How to make it.** Step 6: clean and dry the slab, spread the mixed epoxy, press the puck in with a slight twist, smooth the squeeze-out.

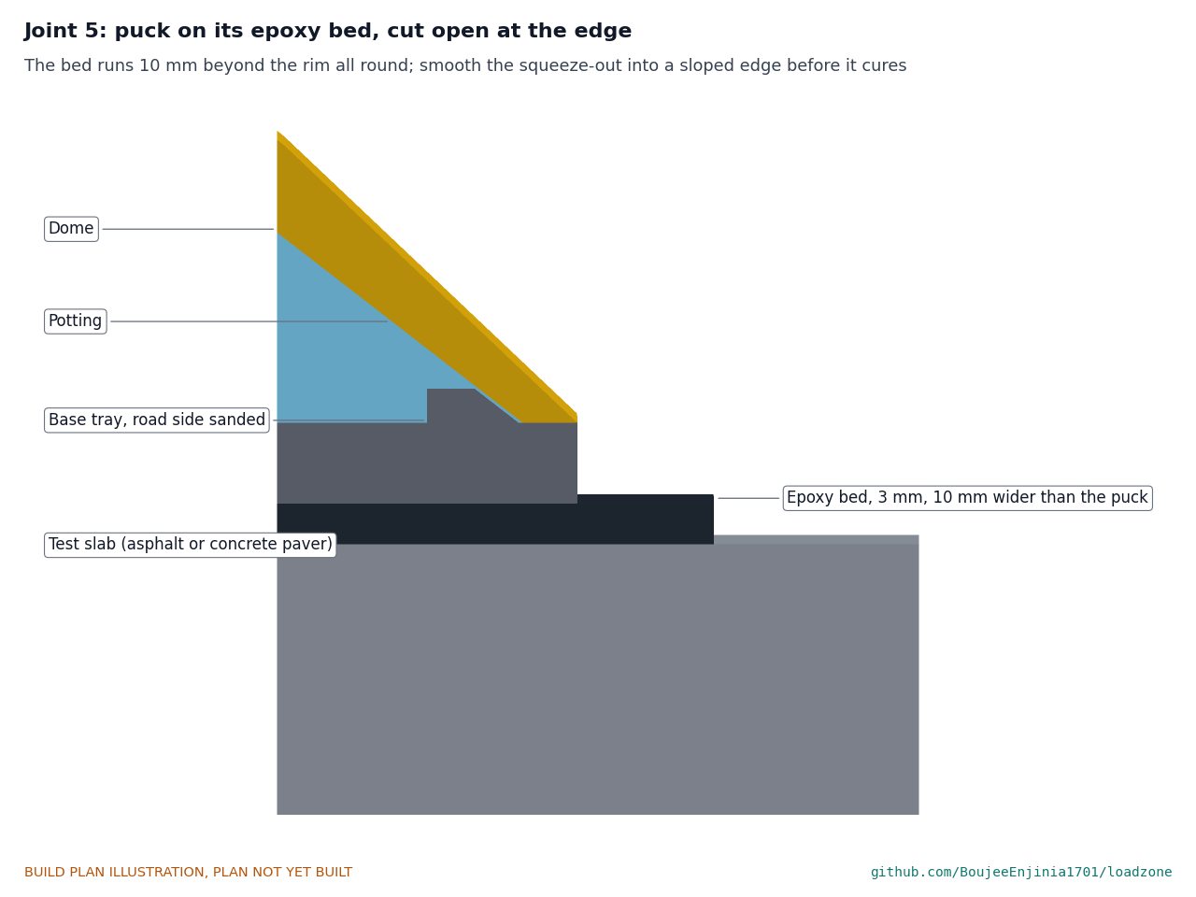
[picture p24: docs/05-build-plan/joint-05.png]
Figure 12. Joint 5: puck on its epoxy bed, cut open at the edge


*Figure 12. The bed runs 10 mm beyond the rim all round and is smoothed into a sloped edge.*

**How it fits the parts next to it.** The bed bonds the sanded road side of the tray to the slab; the fill and vent holes are under it.

**Check before moving on.** The bed is even all round, with no gap under the rim edge; after cure the puck does not move under a hard push by hand.

### 3.9 Sign brackets (make 2; sign option)

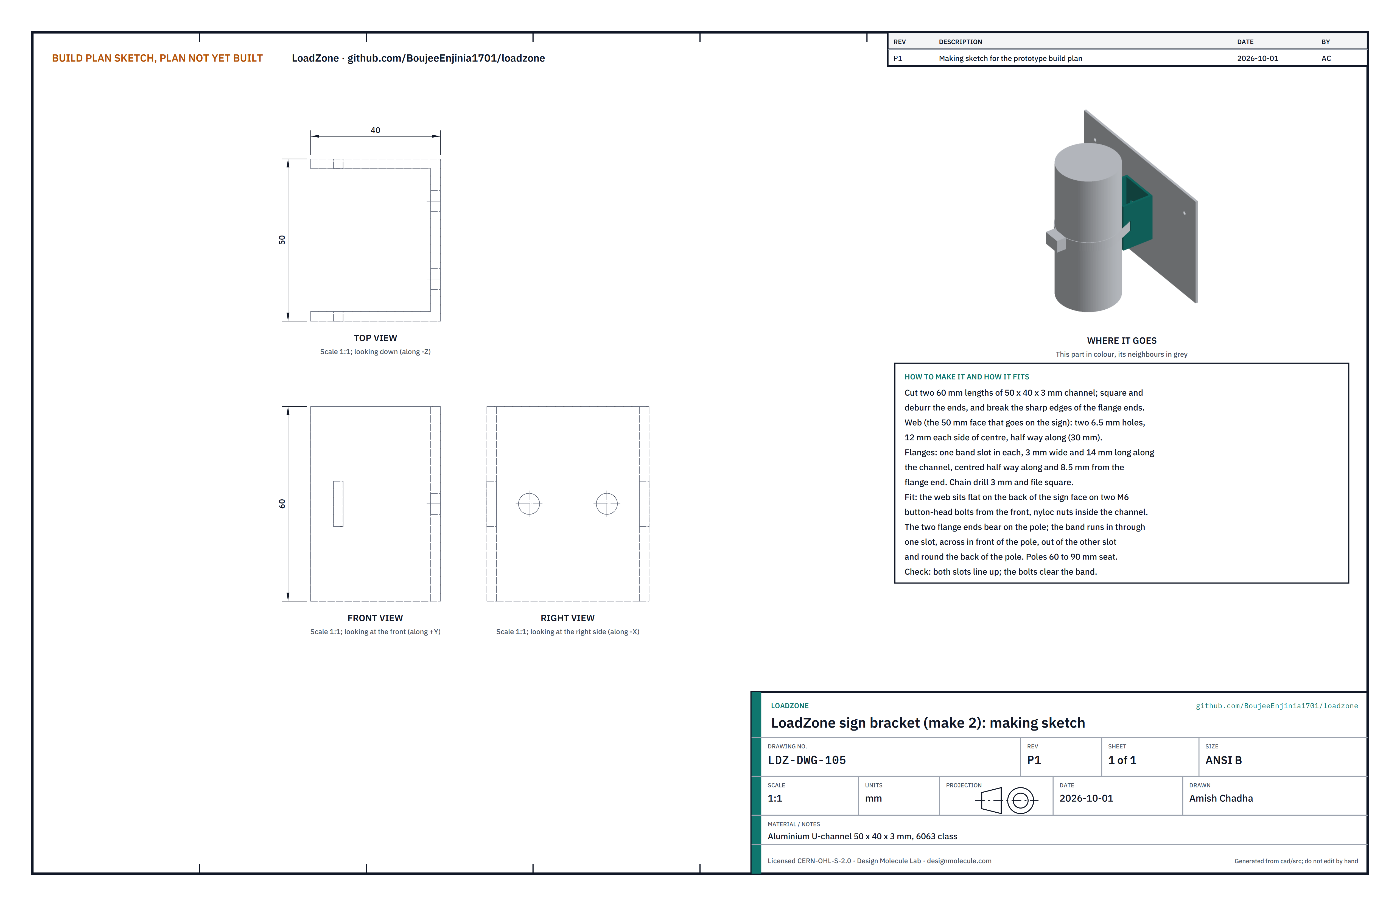
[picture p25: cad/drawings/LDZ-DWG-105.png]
Figure 13. Making sketch of the sign bracket


*Figure 13. Sign bracket making sketch (LDZ-DWG-105).*

**What it is and what it is made from.** A short length of channel that bolts to the back of the sign and bears on the pole, with a band clamp through it. Aluminium U-channel 50 x 40 x 3 mm, 6063 class.

**How to make it.**

1. Cut two 60 mm lengths; square and deburr the ends and break the sharp edges of the flange ends, which bear on the pole.
2. In the web (the 50 mm face), drill two 6.5 mm holes, 12 mm each side of centre and half way along.
3. In each flange, cut a band slot 3 mm wide and 14 mm long along the channel, centred half way along and 8.5 mm from the flange end: chain drill 3 mm and file square. Drill the two brackets clamped together so the slots line up.

**How it fits the parts next to it.**

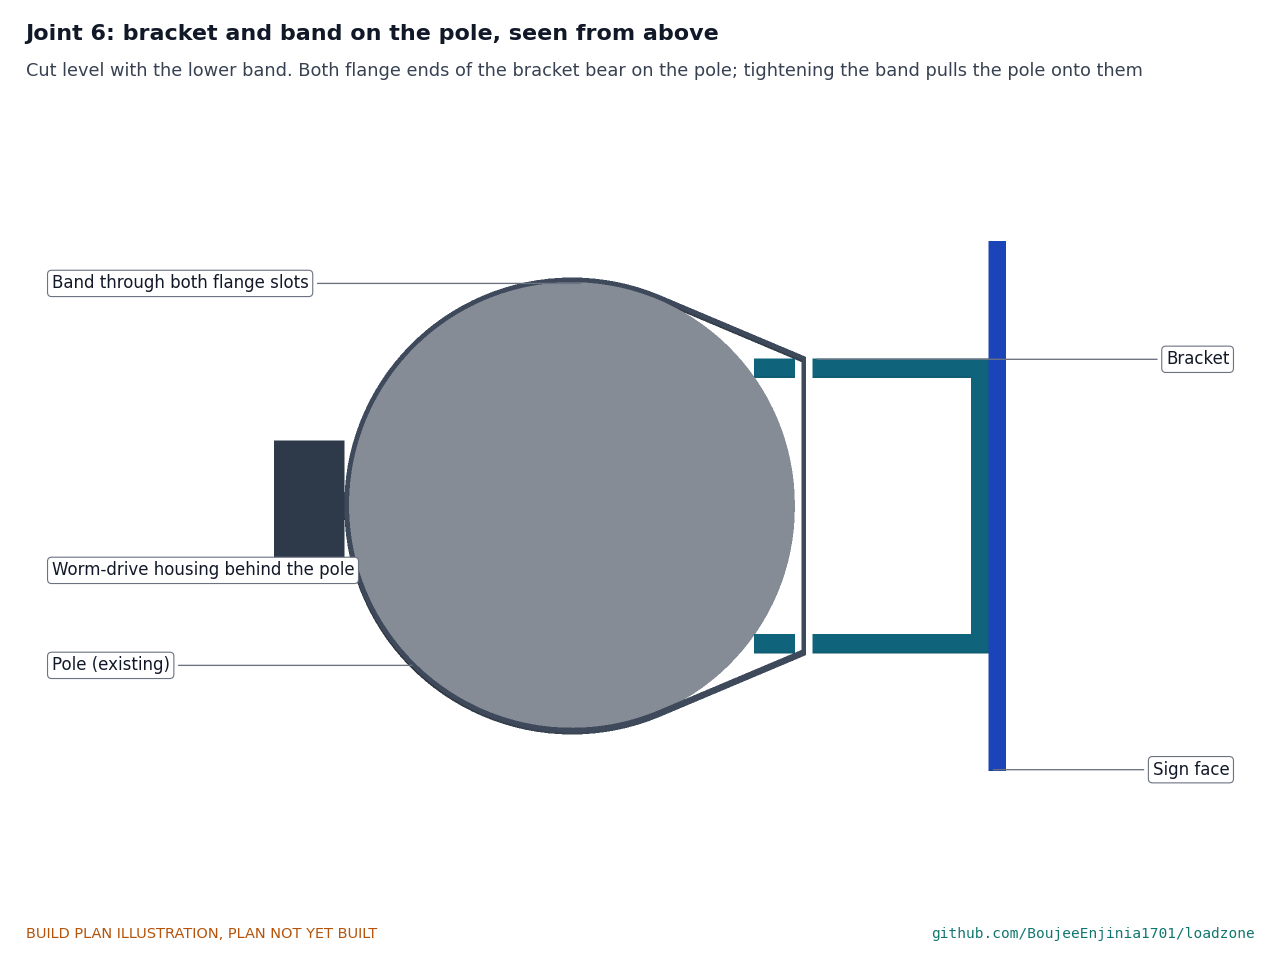
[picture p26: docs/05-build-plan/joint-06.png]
Figure 14. Joint 6: bracket and band on the pole, seen from above


*Figure 14. Both flange ends bear on the pole; the band runs in through one slot, across in front of the pole, out of the other and round the back of the pole.*

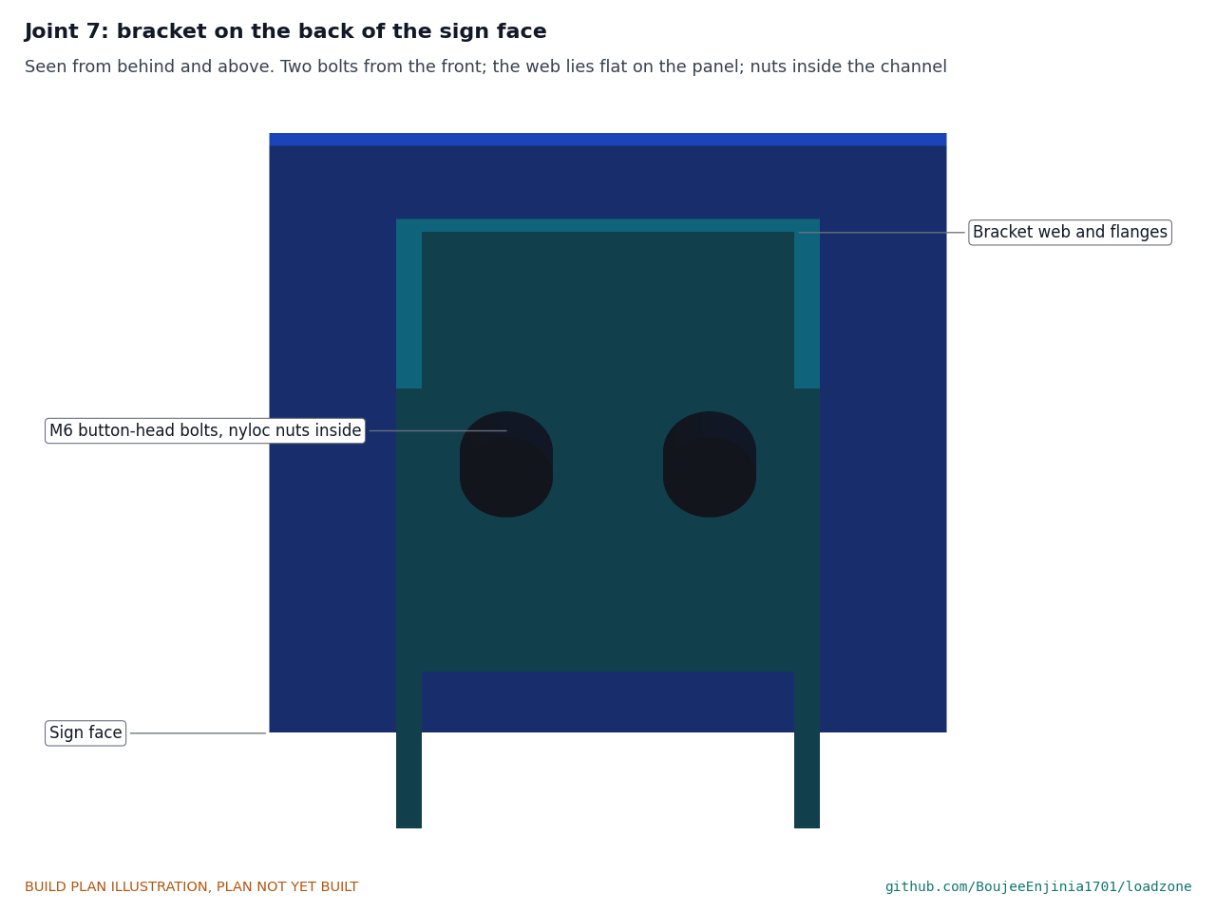
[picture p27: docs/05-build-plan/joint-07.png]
Figure 15. Joint 7: bracket on the back of the sign face


*Figure 15. The web lies flat on the back of the sign, held by two M6 button-head bolts from the printed side with nyloc nuts inside the channel.*

The web lies flat on the back of the sign face, 100 mm from its top or bottom edge. The flange ends stand 40 mm off the sign and bear on the pole; the sign face ends up 33 mm from the pole's surface. Any pole from 60 to 90 mm seats on both flange ends. When the band is tightened, the worm-drive housing sits behind the pole.

**Check before moving on.** Both slots line up; with the bolts fitted, a band passes through both slots without touching a nut.

### 3.10 Sign face (sign option)

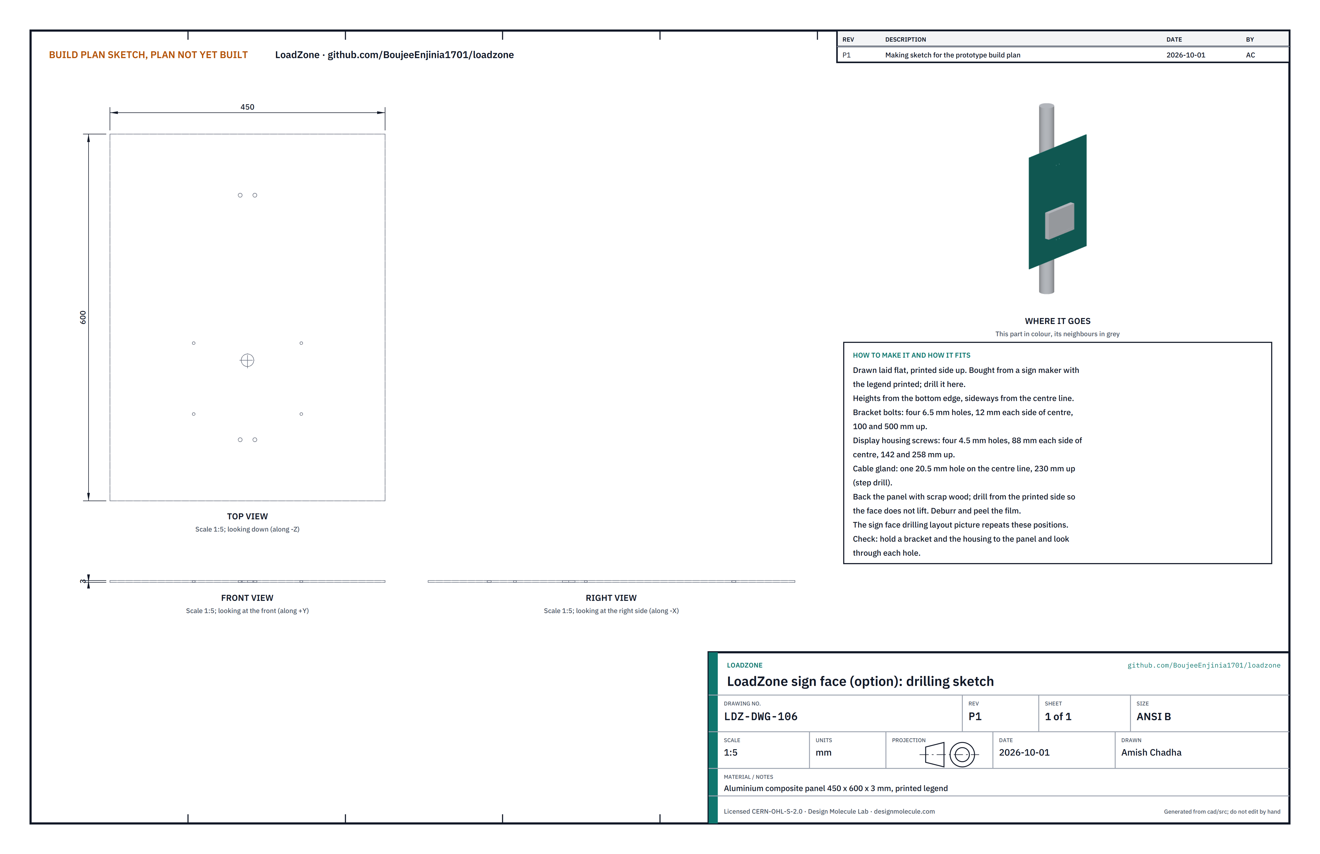
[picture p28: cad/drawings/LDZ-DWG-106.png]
Figure 16. Drilling sketch of the sign face


*Figure 16. Sign face drilling sketch (LDZ-DWG-106), drawn laid flat.*

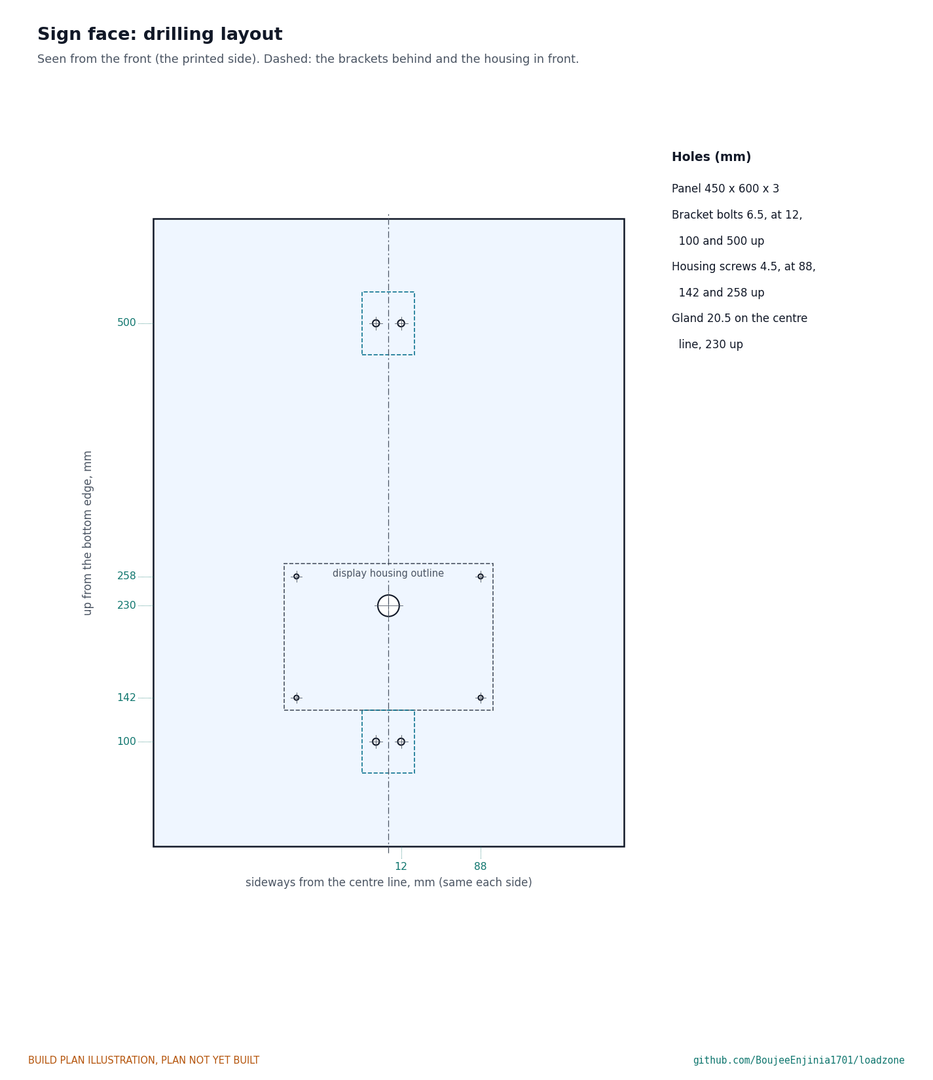
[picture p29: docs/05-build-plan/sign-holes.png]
Figure 17. Sign face drilling layout


*Figure 17. Every hole on the sign face, seen from the printed side.*

**What it is and what it is made from.** The "Loading zone" sign: an aluminium composite panel, 450 x 600 x 3 mm, bought from a sign maker with the legend printed. For the workshop prototype the legend is a placeholder; a sign for a street gets a legend drawn to the trial city's sign rules (in the US, the MUTCD) and approved by the city traffic engineer before it is mounted.

**How to make it.**

1. Lay the panel printed side up on scrap wood. Mark the holes from Figure 17.
2. Bracket bolts: four 6.5 mm holes, 12 mm each side of centre, 100 and 500 mm up.
3. Housing screws: four 4.5 mm holes, 88 mm each side of centre, 142 and 258 mm up.
4. Cable gland: one 20.5 mm hole on the centre line, 230 mm up, with a step drill.
5. Drill from the printed side so the face does not lift; deburr and peel the film.

**How it fits the parts next to it.** The brackets bolt to its back (Figure 15) and the display housing screws to its front (Figure 19).

**Check before moving on.** Hold a bracket and the housing to the panel and look through each hole.

### 3.11 Display housing (sign option)

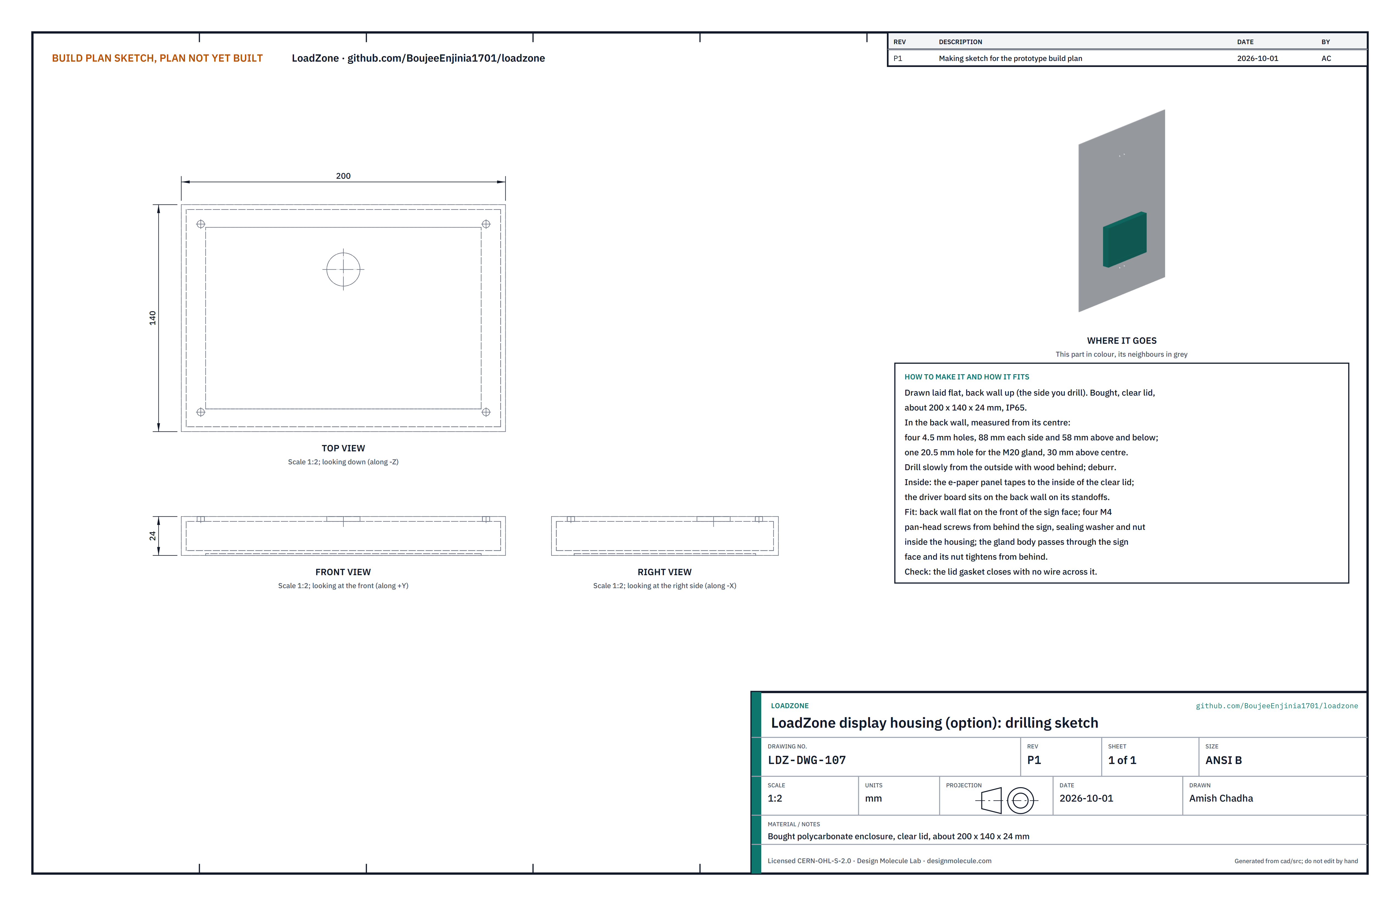
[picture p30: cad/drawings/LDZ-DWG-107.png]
Figure 18. Drilling sketch of the display housing


*Figure 18. Display housing drilling sketch (LDZ-DWG-107), drawn back wall up.*

**What it is and what it is made from.** A bought polycarbonate enclosure with a clear lid, about 200 x 140 x 24 mm, rated IP65, holding a 7.5 inch e-paper panel and its driver board.

**How to make it.**

1. In the back wall, drill four 4.5 mm holes, 88 mm each side of centre and 58 mm above and below it, and one 20.5 mm hole for the gland 30 mm above centre. Drill slowly from the outside with wood behind, and deburr.
2. Tape the e-paper panel to the inside of the clear lid, display side out, and fix the driver board to the back wall on its standoffs.
3. Fit the M20 gland body through the back wall from inside, with its lock nut inside, and pass the cable from the host FieldNode through it to the driver board.

**How it fits the parts next to it.**

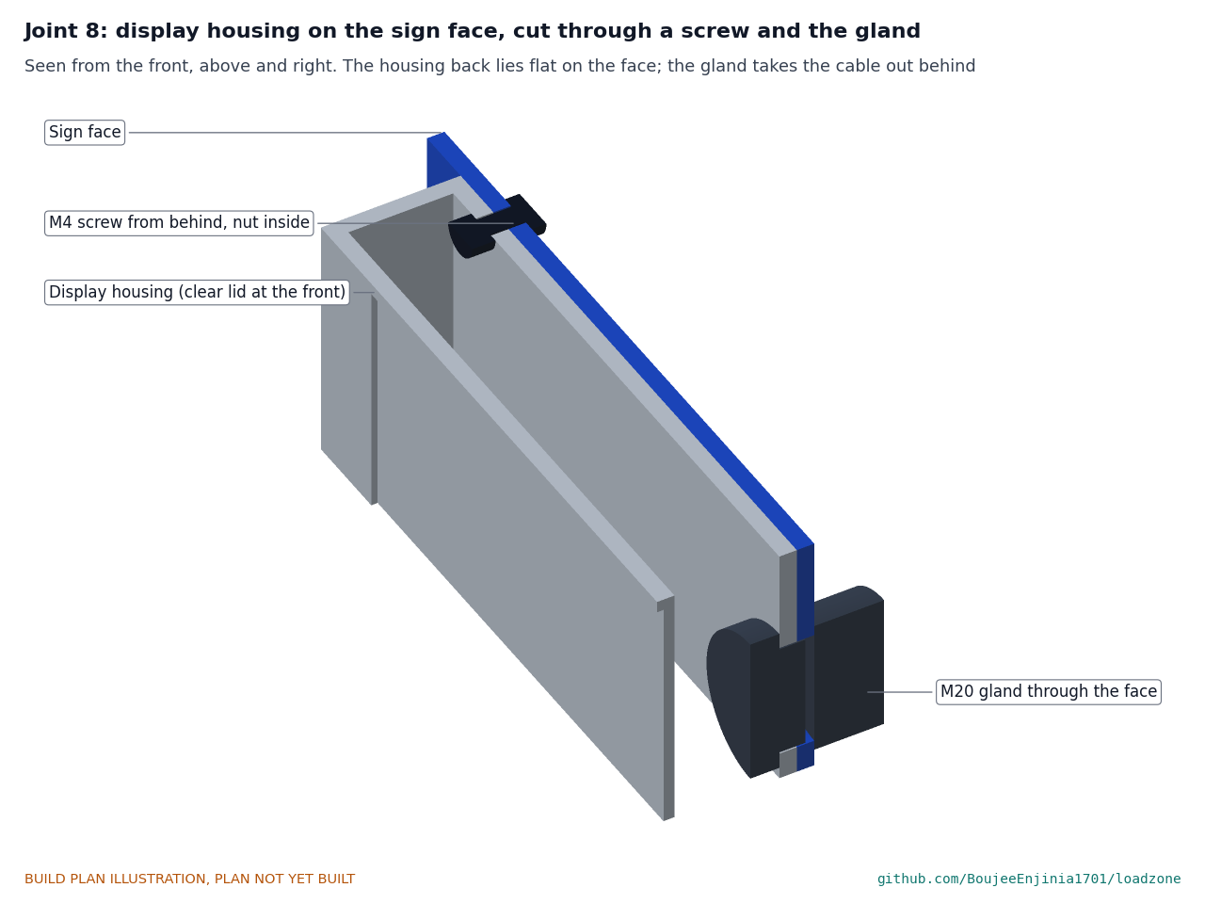
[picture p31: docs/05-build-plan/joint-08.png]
Figure 19. Joint 8: display housing on the sign face, cut through a screw and the gland


*Figure 19. The housing back lies flat on the sign face; four M4 screws come from behind the sign; the gland passes through the face so the cable runs behind the sign.*

**Check before moving on.** The lid closes on its gasket with no wire across it; the gland nut is tight.

### 3.12 Bought components

Buy to specification, not brand. Line numbers are those of the bill of materials.

- **Magnetometer (line 2).** 3-axis, 16-bit, LIS2MDL class, I2C, on a breakout about 22 x 18 mm.
- **Radio module (line 3).** STM32WL-class LoRaWAN module (RAK3172 or Wio-E5 class), with a 2 MB SPI memory chip, two Schottky diodes, a 0.5 A fuse and a 36 x 56 mm piece of prototyping board.
- **Antenna (line 4).** Flexible printed antenna for 915 MHz (the US915 band, the default), adhesive backed, with a u.FL lead.
- **Cells and capacitor (line 5).** Two AA-size lithium thionyl chloride bobbin cells (ER14505 class, about 2.6 Ah) with factory-welded solder tabs, from a maker that publishes a data sheet; one hybrid pulse capacitor rated to 85 °C, at least 31 mF equivalent.
- **Potting (line 6).** Semi-rigid polyurethane potting for electronics, low exotherm, about 175 cm³ per puck; PETG and ASA filament for the prints.
- **Epoxy (line 7).** Two-part road-marker epoxy for raised pavement markers, about 70 cm³ per puck.
- **Sign face (line 8).** Aluminium composite panel 450 x 600 x 3 mm with the printed legend.
- **Display (line 9).** 7.5 inch e-paper panel, 800 x 480, with a driver board that takes commands from the host FieldNode; polycarbonate enclosure with a clear lid; four M4 x 12 pan-head screws with sealing washers and nuts; one M20 cable gland.
- **Brackets (line 10).** 60 mm lengths of 50 x 40 x 3 mm aluminium channel, two 12 mm stainless worm-drive band clamps for 60 to 90 mm poles, four M6 x 16 stainless button-head bolts with nyloc nuts.
- **Hardware and consumables (line 12).** Wire, heat shrink, M2 x 5 self-tapping screws, polyurethane sealant, mould release, cleaning solvent.
- **Casting tooling (line 13).** PETG filament for the master and core plug, about 1 kg of addition-cure silicone mould rubber, rigid casting polyurethane with yellow pigment and UV stabiliser (line 1).

## 4. Putting it together

In each picture the parts already fitted are grey and the part being fitted is in colour, with an arrow showing the way it goes in. Steps 1 and 2 make the dome (sections 3.2 to 3.4); steps 3 to 6 build one puck, so do them twice; steps 7 to 9 build the sign option.

### Step 1: make the silicone mould

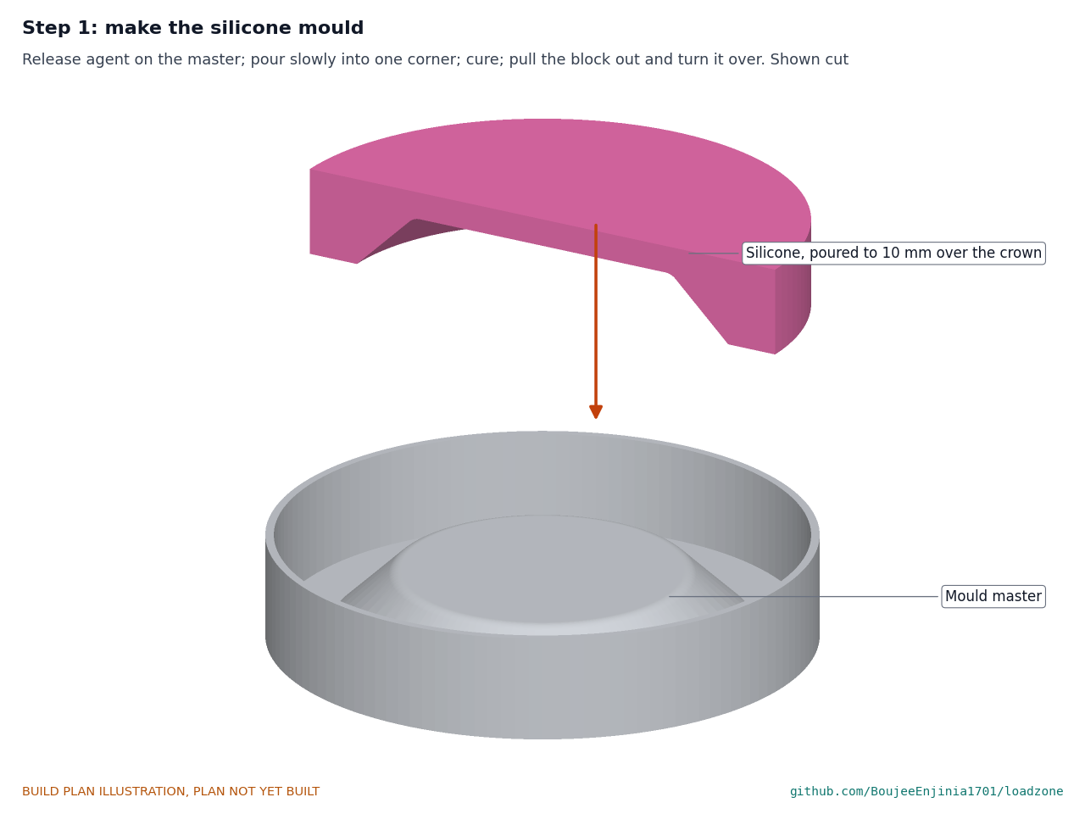
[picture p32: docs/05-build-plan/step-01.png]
Step 1


Release agent on the master; pour the silicone slowly into one corner until it stands 10 mm over the crown; cure; pull the block out and turn it over.

### Step 2: cast the dome

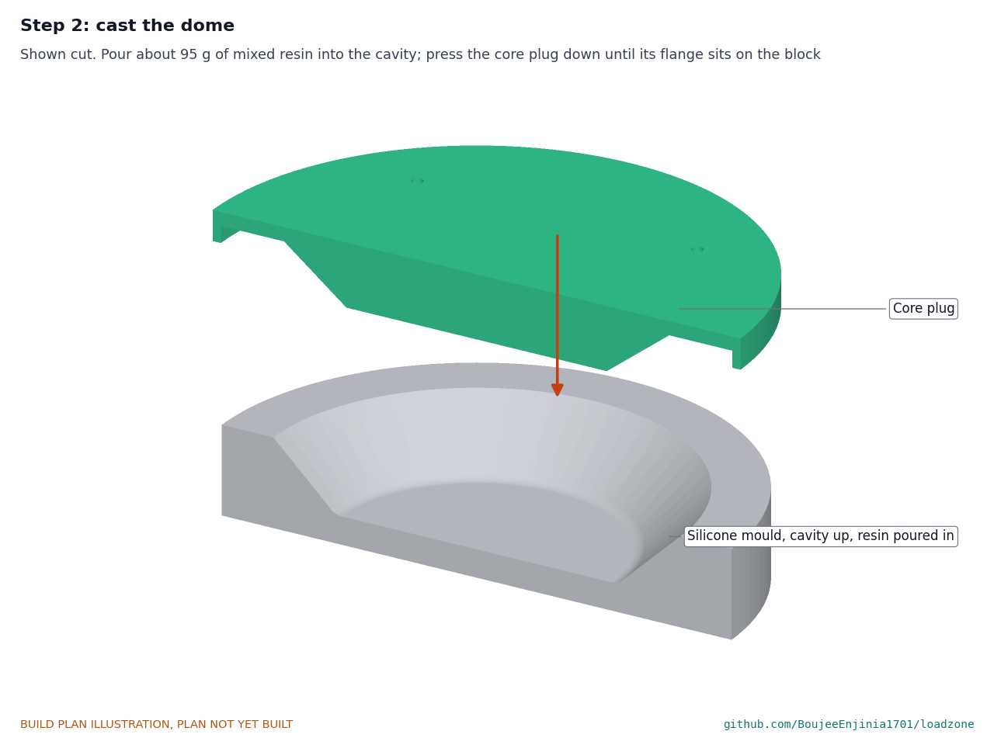
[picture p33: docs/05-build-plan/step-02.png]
Step 2


About 95 g of mixed resin into the cavity; press the core plug down until its flange sits on the block; demould, post-cure and trim (section 3.4).

### Step 3: electronics onto the base tray

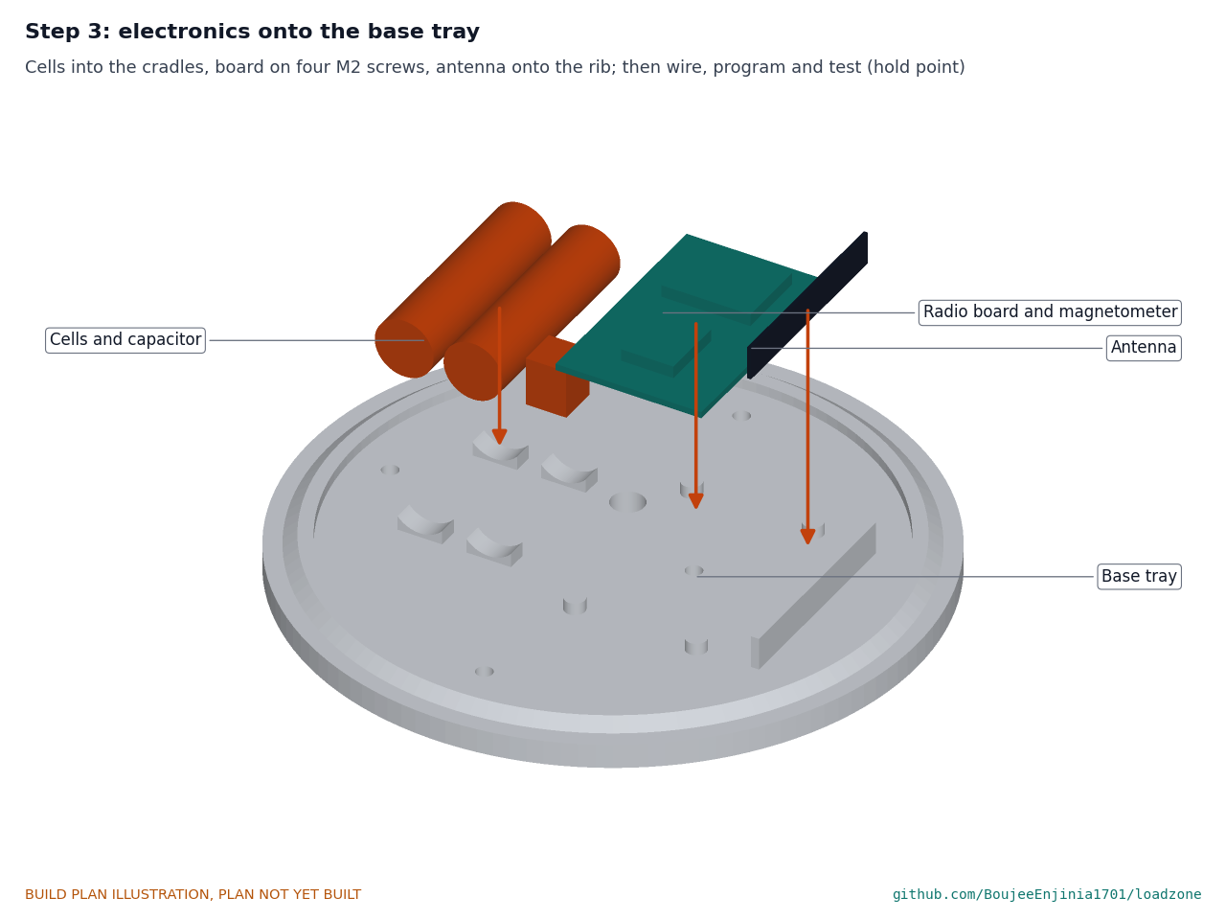
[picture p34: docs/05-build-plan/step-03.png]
Step 3


Cells into their cradles, board on four M2 screws, antenna onto the rib, capacitor in place; wire as Figure 10. **Hold point:** the board is programmed and passes the bench checks of section 5 (rail voltage, sleep current, a received uplink) before the dome goes on. Nothing can be changed after step 5.

### Step 4: dome onto the base tray

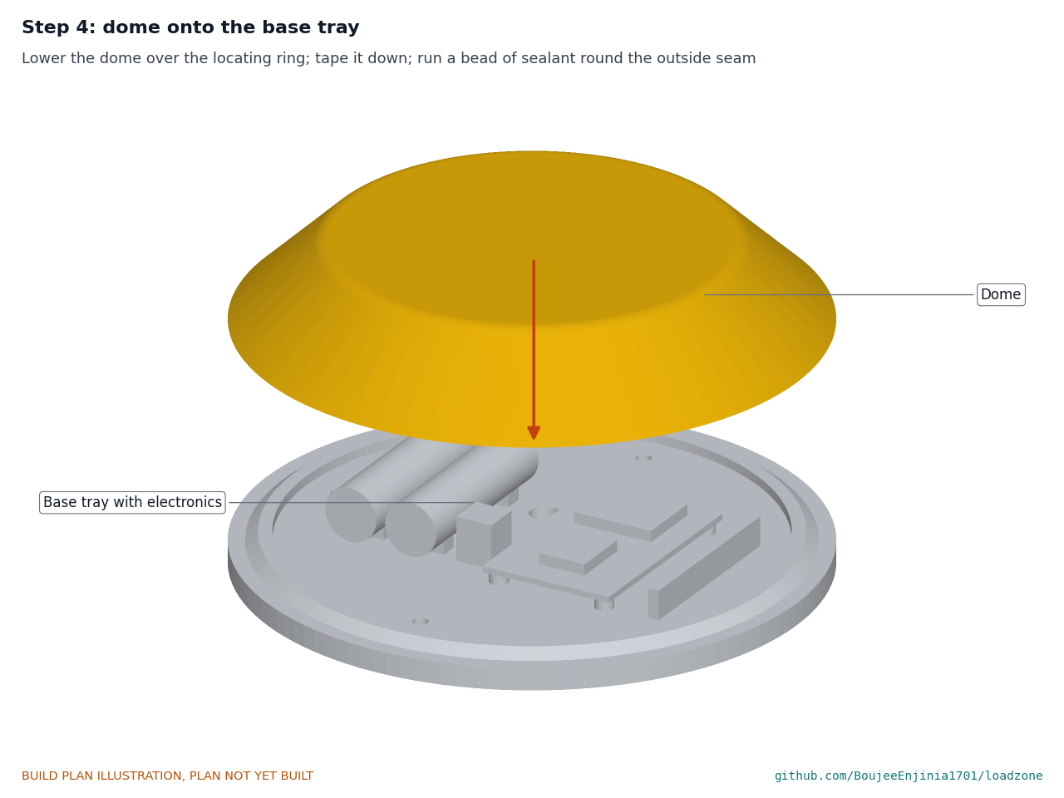
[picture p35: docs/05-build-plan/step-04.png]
Step 4


Lower the dome over the locating ring until the rim sits flat on the disc. Tape it down with two strips across the crown, and run a bead of polyurethane sealant round the outside of the seam. Let the sealant skin over.

### Step 5: pot the puck, upside down

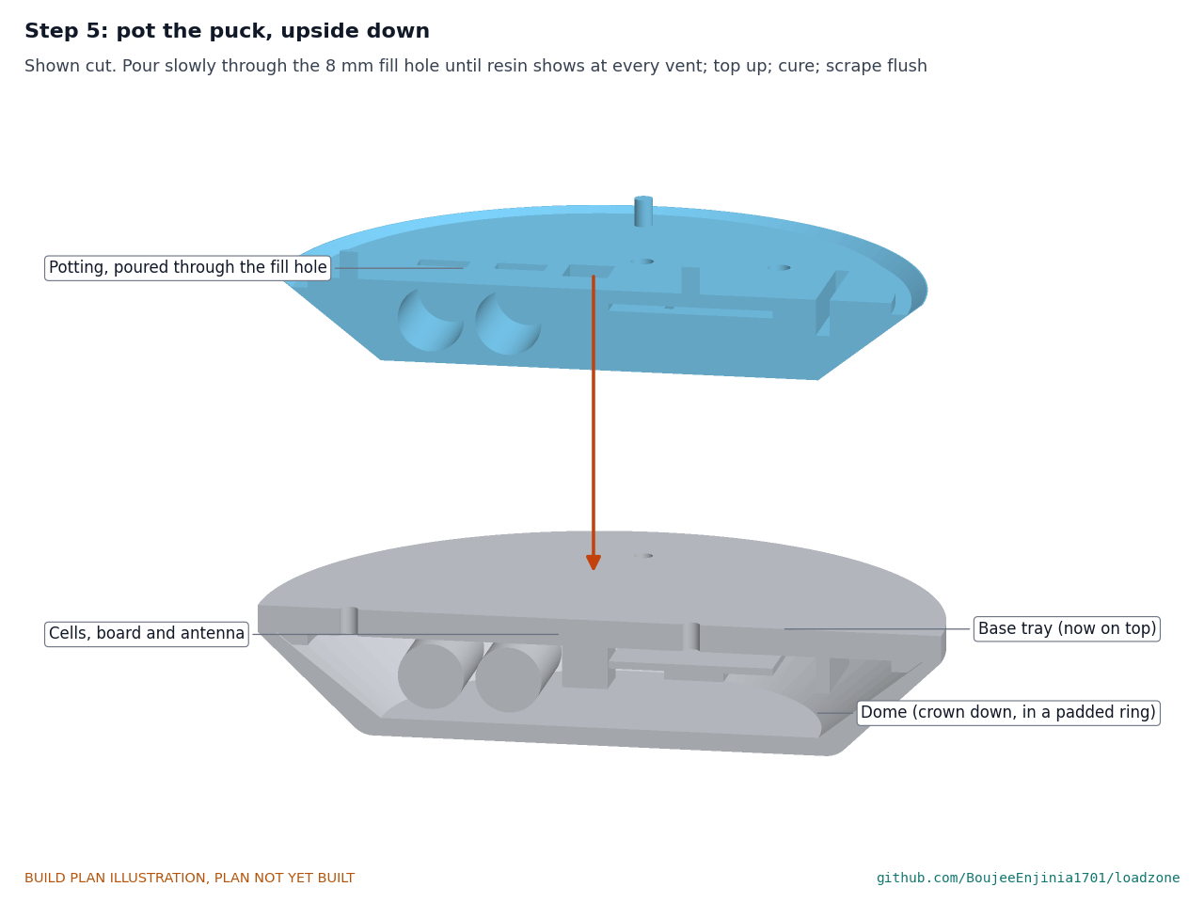
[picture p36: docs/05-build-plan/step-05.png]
Step 5


Set the puck crown down in a padded ring so the tray is level and on top. Pour the mixed potting slowly through the fill hole until it stands in every vent; wait ten minutes for air to rise, and top up. Cure at room temperature as the maker says, then scrape the fill hole and vents flush with the road side. **Hold point:** safety stop S4 in section 6.

### Step 6: bond the puck to a test slab

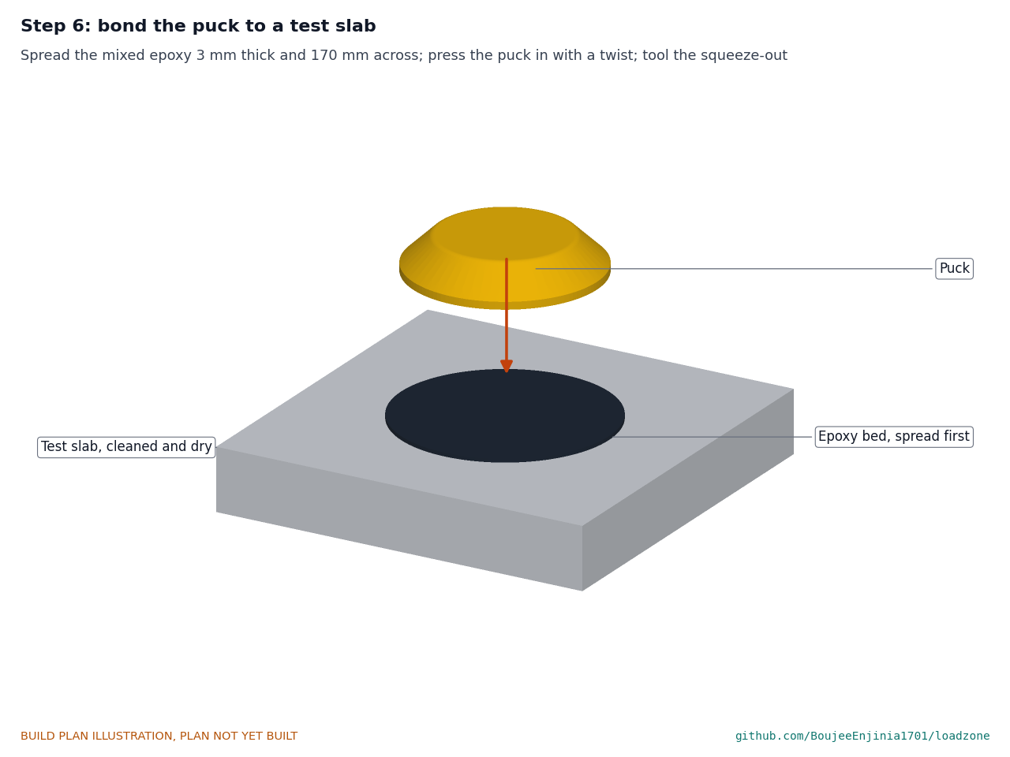
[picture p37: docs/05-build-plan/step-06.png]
Step 6


Clean and dry the slab. Spread the mixed epoxy 3 mm thick and 170 mm across, press the puck in with a slight twist until the bed squeezes out 10 mm all round, and smooth the edge into a slope. Leave it to cure for the maker's full time before any load.

### Step 7: brackets onto the back of the sign

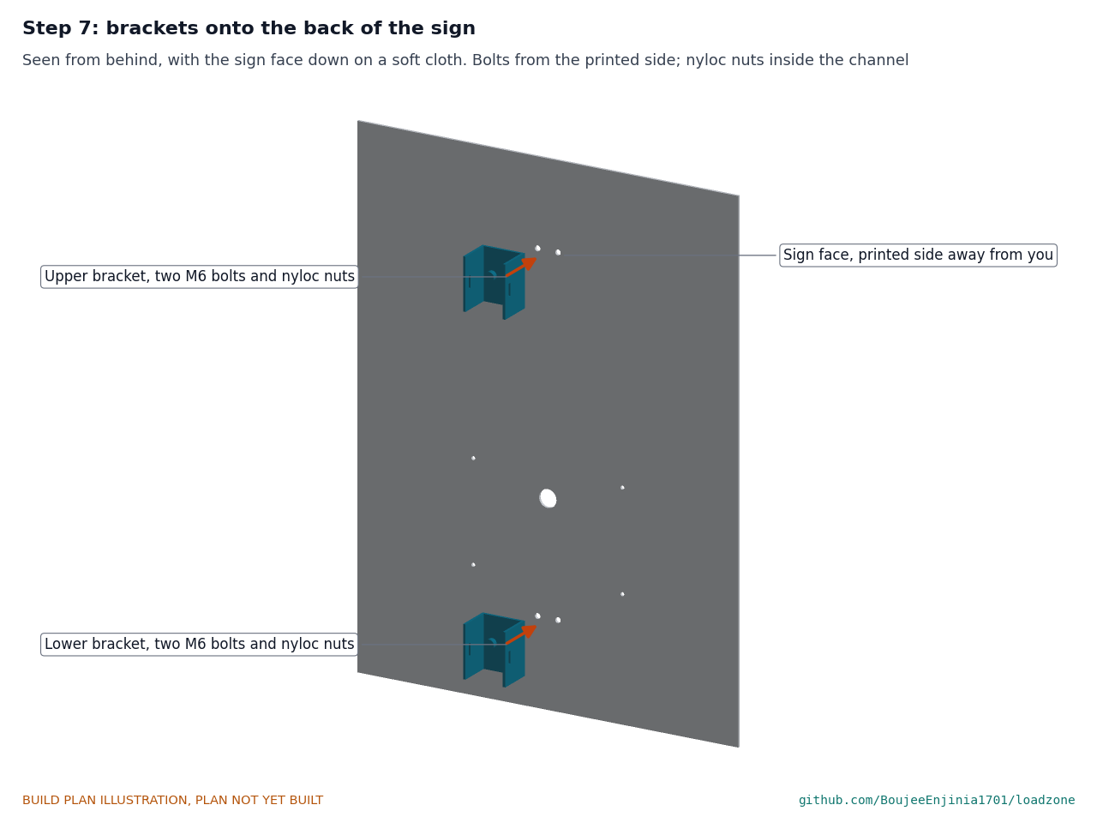
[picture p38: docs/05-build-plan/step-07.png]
Step 7


Sign face down on a soft cloth. Each bracket on two M6 button-head bolts from the printed side, nyloc nuts inside the channel, flanges pointing away from the sign. Tighten firmly without crushing the panel.

### Step 8: display housing onto the sign face

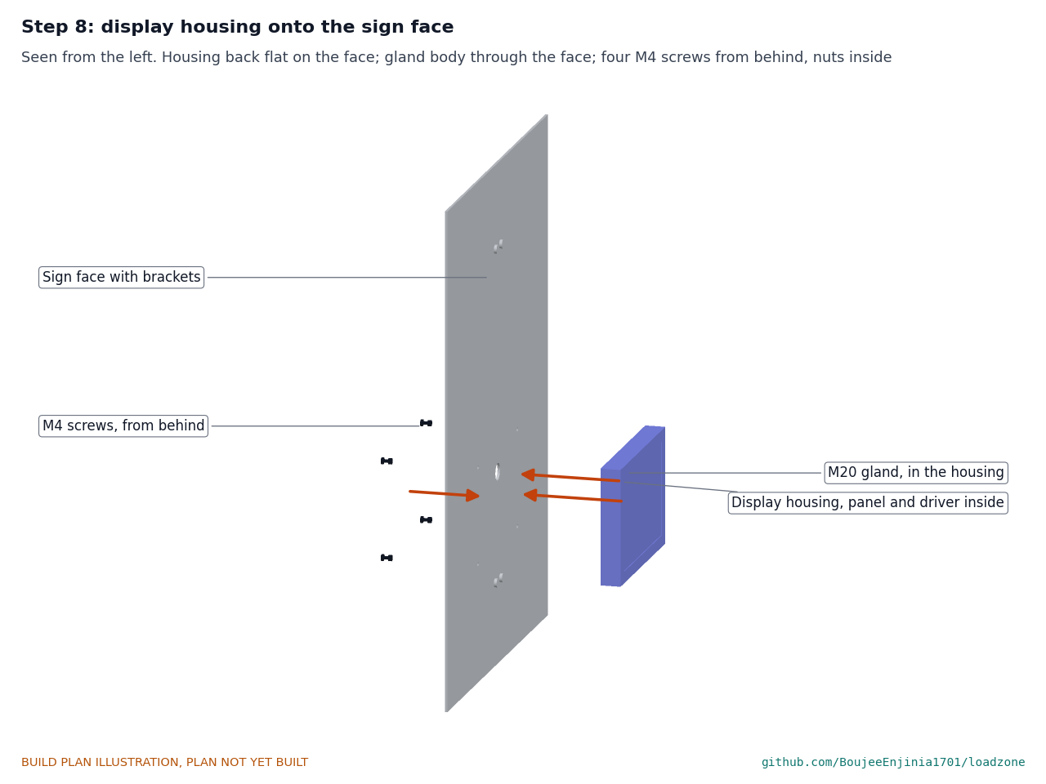
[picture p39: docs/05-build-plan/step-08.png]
Step 8


Panel and driver already fitted (section 3.11). Hold the housing's back flat on the printed face with the gland body through the 20.5 mm hole; four M4 screws from behind the sign with sealing washers and nuts inside the housing; tighten the gland nut behind the sign.

### Step 9: sign onto the pole stub

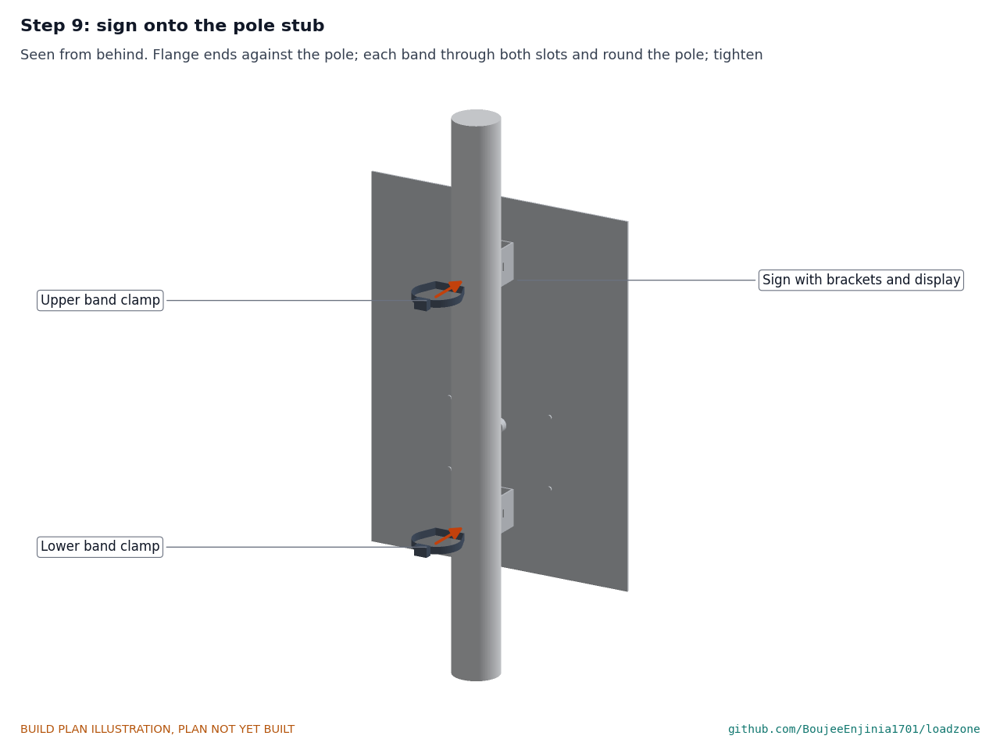
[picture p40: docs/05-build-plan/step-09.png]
Step 9


Seen from behind. Clamp a 1 m length of 76 mm pole upright in a stand. Hold the sign with both flange ends of each bracket against the pole; pass each band through both slots of its bracket and round the back of the pole, with the worm-drive housing behind the pole; tighten both bands. Run the display cable down behind the sign to the host FieldNode's sensor port, which is built to the FieldNode build plan. **Hold point:** safety stop S7 in section 6.

## 5. First checks

These are the checks a TRL 4 test report would record; this plan only lists them. Requirement numbers are those of LDZ-REQ-001.

*Table 2. First checks.*

| Check | Requirement | How | Pass when |
| --- | --- | --- | --- |
| Diodes block back-feed | Safety, R3 | Before the second cell goes in: one cell fitted, measure from the rail to the empty cell's tab | No voltage at the empty tab beyond leakage |
| Supply rail and sleep current | R3 | Bench, before the dome: rail voltage; current in sleep with a meter on its microamp range | About 3.4 V; sleep current near 6 µA |
| Magnetometer sees steel | R1 | Bench: move a steel plate about 1 kg over the board at 300 mm and away again | The reading changes by well over the 3 µT threshold and returns |
| Report time | R2 | Bench, puck near a gateway: change state with the steel plate; time to the state at the server | 60 s or less |
| Airtime at SF9 | R5 | Gateway log of one uplink | About 206 ms on air for the 11-byte payload |
| Only state and health leave the puck | R9 | Decode an uplink at the server | State, time since change, confidence, voltage, temperature, nothing else |
| Potting complete | R8 | After cure: vents full, tap test round the dome | No hollow spot; resin flush at every hole |
| Height and edge | R7 | Measure the bonded puck on the slab | 35 mm or less above the slab; no sharp edge |
| Bond by hand | R6, R14 | After cure, push the puck hard sideways by hand; time the bonding of the second puck | No movement; bonding takes 15 min or less for two people |
| Link from under a vehicle | R4 | Park a van over a bonded puck on its slab outdoors, gateway 300 m away | Uplinks received at SF9 or faster |
| Sign legibility | R11 | By day, show a two-digit count; read it from 25 m | Digits readable at 25 m |
| Sign power | R12 | Measure the sign's average draw from the host FieldNode over a day | Well under the FieldNode's 100 mW allowance (about 18 mW expected) |
| Sign on the pole | R11 | Push the sign's corners by hand on the pole stub | Nothing turns or slips at the bands |

## 6. Safety stops

Stop at each point. Carry on only when everything listed is true.

- **S1. Before the cells come into the workshop.** Cells from a maker with a data sheet, with factory-welded solder tabs, at about 3.6 V each with no dents, leaks or swelling. A fireproof place to store them, away from metal tools. Never charge, short, heat, crush or open a lithium thionyl chloride cell.
- **S2. Before the second cell is wired.** The diodes and the fuse are fitted and their direction checked with a meter, so neither cell can ever charge the other. Solder only to the tabs, quickly, never to the can.
- **S3. Before any casting, potting or bonding.** Ventilated space; nitrile gloves, eye protection and, for polyurethane resins and potting, a respirator rated for isocyanates; each maker's safety data sheet read; spills cleaned with the solvent the data sheet names.
- **S4. Before potting over live cells.** The bench checks of section 5 pass; the potting is a low-exotherm grade and the data sheet's peak temperature for about 175 cm³ is well below the cells' rating; pour at room temperature, never in a heated oven.
- **S5. Before bonding with hot-applied epoxy (if that grade is used).** Burn protection: heat-resistant gloves, long sleeves, and the heater on a stable surface.
- **S6. Before any puck goes on a real road (outside this plan).** A road authority permit, a trained crew, the traffic management that local rules require, high-visibility clothing; never from a live lane; away from bike lanes and crossings.
- **S7. Before the sign goes on the pole stub.** Sign and bracket edges deburred; band tails cut and capped; the stub clamped so it cannot tip under the sign; hands clear when tightening the bands.
- **S8. Before any street pole installation (outside this plan).** Work from a stable platform with a second person; clear of overhead power lines; the pole owner's permission for the added wind load.
- **S9. At end of life.** Spent pucks and cells go to hazardous-waste recycling as primary lithium cells; never cut a puck open.

## 7. Tools, skills and workspace

**Tools.** Enclosed 3D printer with a bed of at least 200 x 200 mm that prints ASA and PETG; digital scale reading 0.1 g; mixing cups, sticks and a timer; vacuum chamber for degassing (useful, not essential); sandpaper to 400 grit; sharp trimming knife; soldering iron with a fine tip; wire strippers and heat-shrink gun; multimeter with a microamp range; a debug programmer for the radio module (ST-LINK class) and access to a LoRaWAN gateway and network server; hacksaw with a 24 teeth per inch blade; bench drill or drill in a stand; drills 2 to 6.5 mm and a step drill to 22 mm; flat and needle files; scriber, square, steel rule and calipers; screwdriver for the band clamps; pole stand or bench clamp for a 1 m pole.

**Skills.** No certified trade is needed. Two-part resin casting and mould making, through-hole soldering, safe handling of primary lithium cells, flashing firmware with a debug programmer, and basic metalwork (marking out, sawing, drilling, filing). All circuits are extra-low voltage, 3.67 V at most in the puck; the sign runs from the host FieldNode. No mains wiring is part of this build.

**Workspace.** A bench about 1.2 x 0.6 m; a ventilated corner for casting, potting and bonding, kept apart from the electronics bench; a fireproof storage place for the cells; a place to leave castings and bonds curing undisturbed for a day.

**Personal protective equipment.** Safety glasses; nitrile gloves for resins and epoxy; a respirator rated for isocyanates when mixing and pouring polyurethane; cut-resistant gloves for aluminium; no gloves near a turning drill.

## 8. Where the numbers come from

- Model and constructability checks: `cad/src/model.py` (`python cad/src/model.py --check`, 92 checks); STEP and STL exports in `cad/step/` and `cad/stl/`.
- Pictures: `cad/src/build_plan_media.py`, using `.kit/build_views.py`; written to `docs/05-build-plan/` and `cad/drawings/LDZ-DWG-101` to `LDZ-DWG-107`.
- General arrangement: `cad/drawings/LDZ-DWG-001.pdf`, Rev P3.
- Calculations: `docs/04-calcs/01-sizing.md` (LDZ-CAL-001 v0.3) and `docs/04-calcs/sizing.py`; mass [G2], loads [F1] to [F4], link [D2], [D3], energy [B1] to [B5], cost [I1].
- Bill of materials: `bom/bom.csv` and `bom/bom-notes.md`.
- Decisions: `docs/decisions/0003-design-for-construction.md` (LDZ-DDR-003), with LDZ-DDR-001 and LDZ-DDR-002; open items in `docs/06-design-decisions.md` (LDZ-DEC-001).
- Requirements: `docs/03-requirements.md` (LDZ-REQ-001 v0.5).

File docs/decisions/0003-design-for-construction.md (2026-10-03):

---
doc_id: LDZ-DDR-003
title: LoadZone design for construction
project: LoadZone
doc_type: Design decision record
version: "0.3"
status: Draft
date: '2026-10-02'
author: Amish Chadha
license: CERN-OHL-S-2.0
revisions:
- version: "0.1"
  date: '2026-10-01'
  author: Amish Chadha
  change: Changes that make the concept physically buildable, with the reason for each; made under Amish's 2026-09-30 instruction to make the design physically buildable; open for his review
- version: "0.2"
  date: '2026-10-02'
  author: Amish Chadha
  change: Accepted by Amish on 2026-10-02, including the recommendations for A1 to A3
- version: "0.3"
  date: '2026-10-02'
  author: Amish Chadha
  change: Appearance model updated to the constructable sign brackets and puck internals; renders remain for the Mac
---

# 0003: Design for construction

- **Date:** 2026-10-01
- **Status:** accepted. Amish, 2026-10-02: "i approve your recommendations for all 555 open decisions." This covers every change in Tables 1 and 2, as made, and the recommendations for A1 to A3 in Table 3, which are now decided as recommended and recorded in the design decisions register (LDZ-DEC-001).

## Context

On 2026-09-30 Amish asked for every repo to get an illustrated prototype build plan and wrote: "If you are realising that the design cannot be built as per concept - fix the design assumptions to match and be physically feasible as you draw the illustrations." The concept model of LDZ-DDR-002 showed what LoadZone does: a cast dome over potted electronics on a flat base, bonded to the road, and an optional e-paper sign on a pole. Checking it part by part, and with build123d (overlaps, contacts and clearances), found that it could not be built as drawn: the dome had no joint to the base and no way to be potted, the parts inside floated, the cells sat 1.2 mm from the dome wall, the casting method was a phrase rather than a process, and the sign was held to its pole by solid rings that cannot be made or fitted.

The changes keep what LoadZone does: the same puck outside (150 mm across, 31 mm high, the same dome and crown), the same cells, radio, magnetometer, antenna, potting and epoxy bed, the same slot-centre placement, and the same sign face, display and pole mounting height. Nothing here changes the pitch or the safety case. Every change is in `cad/src/model.py`, which now runs 92 constructability checks (`python cad/src/model.py --check`): nothing overlaps, every part touches the part that holds it, and clearances for potting, tabs and leads are met. All 92 pass.

## Decision

*Table 1. Changes made to the model, the BOM and the calculations.*

| # | Problem in the concept | Change made | Why this way |
| --- | --- | --- | --- |
| P1 | The dome sat on a flat 150 x 6 mm base disc with nothing to locate or seal it, and the cavity was "fully potted" with no way in: potting poured into the open dome before the base went on would trap air under the base, and a closed cavity has no fill path. | The base becomes a printed ASA tray: the same 150 x 6 mm disc plus a tapered locating ring (141.4 mm across at the disc, 135.0 mm at its top, 2.5 mm tall) that fits the dome's cavity with 0.3 mm all round, an 8 mm fill hole and four 4 mm vents through the disc. The dome rim sits flat on the disc, a bead of polyurethane sealant closes the outside seam, and the puck is potted upside down through the fill hole until resin shows at every vent. | Potting from the road side lets air rise to the vents, which are at the highest point when the puck is upside down. The fill and vent holes end up under the epoxy bed, so nothing shows on the finished puck. The ring keeps the dome centred while the sealant cures. |
| P2 | The cells, capacitor, radio board and antenna floated in the cavity (1 to 3 mm above the base) with nothing to hold them while the potting was poured. | Two saddle-shaped cradles per cell (11 x 5 mm, 4 mm tall), four 3 mm board standoffs with pilot holes for M2 screws, and an antenna rib (2 x 50 mm, 8 mm tall) printed on the tray. The capacitor and the antenna stand on the tray. | Every part is held in its place by the tray, so the electronics can be wired, programmed and tested on the bench before the dome goes on. The board keeps its 3 mm gap so potting flows under it; a vent under the board lets the air out. |
| P3 | The cells' end corners were 1.2 mm from the sloping dome wall, with no room for their solder tabs and leads. | Both cells moved 3 mm toward the centre (centres 37 and 20 mm from the axis, 2.5 mm apart) and the pulse capacitor 3 mm with them. | 2.5 mm from the dome wall, enough for the tabs and for potting to flow round them; the cells stay on the side away from the antenna. |
| P4 | The antenna strip stood 1.9 mm from the dome wall with no support. | Antenna moved 2 mm inward (48 mm from the axis) and stuck to the inner face of the rib. | 3.8 mm from the wall; no metal above it and 9.5 mm from the board, as before. |
| P5 | The dome was to be cast in "a printed silicone mould", which names no process: a dome with an inner cavity needs a core as well as an outer mould. | A one-off tooling set: a printed mould master (plate, box wall and the dome's outside shape in one print), a silicone mould cast in it, and a printed core plug whose flange sits on the silicone block, whose skirt centres it, and whose cone forms the cavity. Four 4 mm overflow holes let spare resin and air out. New BOM line 13, one-off tooling, USD 35. | The dome's sides are drafted by about 46 degrees, so it releases from a one-piece open mould and a solid core. The flange sets the 4 mm crown and a flat rim face, which is the face that sits on the tray. |
| P6 | Once potted, the puck's electronics can never be reached again, but the concept had no step for programming or testing them. | Programming pads (SWD and UART) on the radio board; programming and a bench test are a hold point before the dome goes on (build plan step 3). The radio board is a piece of prototyping board carrying the bought module (BOM line 3), since a carrier circuit board is TRL 4 work. | The puck is sealed for life, as the concept intends; later firmware changes can only go over the air (Table 3, A1). |
| P7 | The sign was held by two solid 5 mm rings round the pole with solid arms that only touched the back of the sign: a closed ring cannot be fitted to a pole and the arms had no fixing. | Two brackets cut from 50 x 40 x 3 mm aluminium U-channel, 60 mm long, each bolted to the back of the sign face by two M6 button-head bolts, with a 12 mm stainless worm-drive band clamp that passes through a slot in each flange, across in front of the pole and round its back. The two flange ends bear on the pole; any pole from 60 to 90 mm seats on both. The sign stands 33 mm off the pole (was 30), set by the channel depth, and the brackets sit 100 mm from the top and bottom edges (was 120) to clear the display housing. BOM line 10 is now this bracket, USD 7 each (was USD 5). | A band clamp is how signs are fixed to street poles; the channel gives a flat face for the sign and two bearing edges for the pole from one stock section. |
| P8 | The display housing was a solid block on the face of the sign with no fixing and no way for its cable to reach the host FieldNode. | A bought polycarbonate enclosure with a clear lid (about 200 x 140 x 24 mm), held by four M4 pan-head screws from behind the sign with sealing washers and nuts inside, and an M20 cable gland through its back wall and a 20.5 mm hole in the sign face, so the cable runs down behind the sign. | Nothing passes through the clear lid; the panel tapes to the inside of the lid and the driver board sits on the back wall. |

*Table 2. Knock-on changes.*

| Item | Change | Reason |
| --- | --- | --- |
| Mass | Unchanged at 451 g without the epoxy bed (LDZ-CAL-001 [G2]): the tray features take the place of potting of about the same density. | Follows the model. |
| Cost | Two-puck kit USD 116.00 (was USD 114.00): line 12 adds sealant, M2 screws and mould release (USD 8.00, was USD 6.00). Value-engineering target USD 120, so USD 4.00 under it. Sign option USD 101.00 (was USD 97.00). One-off casting tooling USD 35.00, not part of the per-kit cost. `budget_usd` unchanged. | Parts added for construction. |
| Drawings | LDZ-DWG-001 Rev P3; making sketches LDZ-DWG-101 to 107 added. | Follows the model. |
| Documents | LDZ-CAL-001 v0.3 (cost), LDZ-REQ-001 v0.5 (R13 against the value-engineering target), LDZ-PRC-001 v0.5 (components table, cost). No requirement changed status. | Follows the model. |
| Loads and link | Unchanged: the dome, crown, base diameter and bed are the same, and the antenna is still at the dome edge with no metal above it. | |

*Table 3. Items proposed, then accepted by Amish as recommended on 2026-10-02.*

| # | Question | Options | Recommendation |
| --- | --- | --- | --- |
| A1 | The potted puck is sealed for life: its cells cannot be replaced and its firmware can only change over the air. | (a) accept, as the fully potted concept implies, and plan over-the-air updates for TRL 4; (b) add a sealed service port, which weakens R8 and R15. | (a). **Accepted 2026-10-02.** |
| A2 | The epoxy bed now bonds to a printed ASA tray. Epoxy keys to sanded ASA, but less well than to cast polyurethane, adding a second bond to the one already at risk under R6. | (a) printed ASA, sanded with 80 grit, checked in the TRL 4 pull-off test; (b) cast the tray in polyurethane in a second simple mould. | (a) for the first prototype; (b) if the pull-off test shows the tray side failing first. **Accepted 2026-10-02.** |
| A3 | The M6 bracket bolts and M4 housing screws show as button heads on the printed face of the sign. | (a) button heads, as modelled; (b) studs bonded to the back of the panel so the face stays clean. | (a) for the prototype. **Accepted 2026-10-02.** |

## Consequences

- `design_state: constructable` in `project.yaml`. The build plan LDZ-BLD-001 shows every component and step in pictures generated from the model (`cad/src/build_plan_media.py`); open items are in the design decisions register LDZ-DEC-001.
- With A1 to A3 accepted, the puck is sealed for life with over-the-air updates planned for TRL 4, the base tray is printed ASA sanded with 80 grit (cast polyurethane if the TRL 4 pull-off test fails on the tray side), and the sign face shows button heads.
- Requirement status is unchanged: none not met, 3 at risk (R1, R5, R6), 1 not verifiable at TRL 3 (R14), 7 met on paper, 4 met by design (LDZ-CAL-001 v0.3). R13 is now reported against the value-engineering target: USD 4.00 under it.
- The appearance model `cad/src/product_model.py` now draws the channel brackets, band clamps and button-head bolts of this record and the moved cells and antenna, taken from the model (2026-10-02). The photoreal renders, `media/card.png` and `media/social-preview.png` are made next on Amish's Mac, where Blender is. The puck's outside is unchanged.
- The display enclosure, the e-paper driver board and the band clamps are chosen at TRL 4; their sizes must be checked then and the holes moved to suit (LDZ-DEC-001, items to confirm).

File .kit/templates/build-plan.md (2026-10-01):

---
doc_id: PRJ-BLD-001
title: Project prototype build plan
project: Project name
doc_type: Build plan
version: "0.1"
status: Draft
date: YYYY-MM-DD
author: Amish Chadha
license: CERN-OHL-S-2.0
revisions:
  - version: "0.1"
    date: YYYY-MM-DD
    author: Amish Chadha
    change: First build plan; design made constructable
---

# Project prototype build plan

**Plan, not yet built.** How to build the first proof-of-concept prototype, component by component. Building and testing to it is TRL 4 work. Decisions still to be made are kept in the design decisions register (`docs/06-design-decisions.md`), not here.

## 1. What you are building

Every component, pulled apart and numbered in build order

One short paragraph: what the prototype is, how many components, which are made and which are bought, and the main ways they are made.

## 2. What changed to make it buildable

| Component | The concept had | The buildable design has | Why |
| --- | --- | --- | --- |

## 3. Making the components

### 3.1 Component name

Making sketch

**What it is and what it is made from.**

**How to make it.**

1. Mark out ...
2. Cut ...

**How it fits the parts next to it.**

Close-up of the joint

**Check before moving on.**

## 4. Putting it together

### Step 1: ...

Step 1

## 5. First checks

| Check | Requirement | How | Pass when |
| --- | --- | --- | --- |

## 6. Safety stops

## 7. Tools, skills and workspace

## 8. Where the numbers come from

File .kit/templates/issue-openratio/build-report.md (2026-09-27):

---
name: Build report
about: Tell us what happened when you built, printed or tested part of this design
title: "Build report: "
labels: build-report
---

This is a research and educational prototype, not a medical device. It is a TRL 3 concept and is not released for fabrication. If you build any part of it, you do so at your own risk. Reports help everyone.

**What you built** (part, sub-assembly or test)

**Materials, tools and settings**

**What worked**

**What did not work, with photos or measurements if you have them**

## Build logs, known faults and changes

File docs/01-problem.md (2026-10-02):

---
doc_id: LDZ-PRB-001
title: LoadZone problem statement
project: LoadZone
doc_type: Problem statement
version: "0.5"
status: Draft
date: '2026-10-02'
author: Amish Chadha
license: CERN-OHL-S-2.0
revisions:
- version: "0.1"
  date: '2026-09-25'
  author: Amish Chadha
  change: Initial scaffold
- version: "0.2"
  date: '2026-09-25'
  author: Amish Chadha
  change: Populate to TRL 2 (users, context, constraints, prior work, out of scope)
- version: "0.3"
  date: '2026-09-25'
  author: Amish Chadha
  change: Reflect LDZ-DDR-001 (budget scope, installation, network) and the gateway distance found in LDZ-CAL-001
- version: "0.4"
  date: '2026-09-25'
  author: Amish Chadha
  change: Recommendations accepted by Amish (DDR-002)
- version: "0.5"
  date: '2026-10-02'
  author: Amish Chadha
  change: First partner type and scope for plowed streets decided on 2026-10-02 (LDZ-DEC-001, items 2 and 7)
---

# LoadZone problem statement

Delivery drivers cannot see whether a loading bay is free before they reach it, so when the bay is taken they double-park in a traffic lane, a bike lane or a crosswalk, and cities have no routine record of how their loading bays are used. LoadZone aims to report the state of each vehicle slot in a loading bay, in real time and without cameras, at a cost low enough for a city, a business district or a community group to try on one street.

## The problem in numbers

Loading bays in busy districts are full much of the day, and many of the vehicles in them are not delivering. In a 2017 observation study of five locations in downtown Seattle, passenger vehicles were 52 % of all vehicles parked in commercial vehicle load zones, and 41 % of commercial vehicles parked in unauthorized locations, rising to 55 to 65 % near retail centers ([Urban Freight Lab, 2019](https://urbanfreightlab.com/publications/the-final-50-feet-of-the-urban-goods-delivery-system-tracking-curb-use-in-seattle/)). The same research group reports that commercial vehicle load zones often reach 90 % occupancy or more during business hours ([Urban Freight Lab, Final 50 Feet](https://urbanfreightlab.com/final-50-feet/)).

Stops are short, so information has to be quick. In the Seattle study, 60 % of delivery vehicles parked for 15 minutes or less and 81 % for 30 minutes or less ([Urban Freight Lab, 2019](https://urbanfreightlab.com/publications/the-final-50-feet-of-the-urban-goods-delivery-system-tracking-curb-use-in-seattle/)). A bay can change state several times an hour, which static signs and occasional manual surveys cannot capture.

Demand keeps growing. Online sales rose from 16 % to 19 % of all retail sales in 2020 ([UNCTAD, 2021](https://unctad.org/news/global-e-commerce-jumps-267-trillion-covid-19-boosts-online-sales)), and in Great Britain van traffic rose 2.3 % to 59.0 billion vehicle miles in the year to September 2024 ([Department for Transport](https://www.gov.uk/government/statistics/provisional-road-traffic-estimates-great-britain-october-2023-to-september-2024)).

## Users and context

| User | Need |
| --- | --- |
| Delivery and service drivers | Know, before arriving, which bay or slot is free; avoid circling and double parking |
| City curb and transport teams | Occupancy, turnover and dwell time by bay and hour, to set bay size, hours and pricing |
| Parking enforcement | Know which bays have overstays without a patrol or a camera |
| Shops and business districts | Shared loading space that works for their suppliers; evidence to request more bays |
| Cyclists and pedestrians | Fewer vans stopped in bike lanes and at crossings |

The setting is an on-street loading bay along a curb, typically long enough for one to three vans, on a street with shops, offices or homes. The street may already have poles (lighting or signs) that a city allows sensors to be fixed to. A LoRaWAN gateway may already exist nearby (a city network, The Things Network or the lab's TwinKit gateway), or one must be added. From road level under a parked van a puck reaches only about 350 m in a street canyon (LDZ-CAL-001), so a gateway within 300 m of the bay is required (R4 as restated, LDZ-DDR-002).

## Prior work

- **Parking occupancy sensing is established.** San Francisco's SFpark pilot (2011 to 2013) collected and published real-time availability for 7,000 of the city's 28,800 metered spaces ([SFMTA](https://www.sfmta.com/projects/sfpark-pilot-program)). Commercial in-ground and surface parking sensors are sold today, usually as closed devices tied to a vendor's platform and subscription.
- **Curb data standards exist.** The Open Mobility Foundation's Curb Data Specification defines a Curbs API for bay locations and rules, an Events API that can take events from sensors, and a Metrics API for dwell time and occupancy ([Open Mobility Foundation](https://www.openmobilityfoundation.org/about-cds/)). An open sensor that can feed this format lets cities compare sensor data with carrier data.
- **Cities are testing digital curbs.** In 2024 a collaborative of cities funded through the US Department of Transportation SMART grants program began comparative research on curb infrastructure, policy and demand, with the Urban Freight Lab ([Urban Freight Lab](https://urbanfreightlab.com/research-projects/open-mobility-foundation-smart-grant-curb-collaborative/)).
- **Low-power magnetometers are cheap and common.** Parts such as the LIS2MDL are 3-axis, 16-bit sensors with a ±50 gauss range, a single-measurement mode and an operating range of -40 to +85 °C ([STMicroelectronics](https://www.st.com/en/mems-and-sensors/lis2mdl.html)).
- **The lab's FieldNode** provides the LoRaWAN radio core, firmware base and, for the sign option, the solar power and pole mount.

What is missing is an open, inspectable bay sensor that a small city or a community group can build, bond to the road and connect to any LoRaWAN server, with data in an open curb format and no camera.

## Constraints

- Garage-buildable prototype, $120 USD or less for a two-slot bay (two pucks). The optional sign and its host FieldNode are costed separately and are outside this budget (LDZ-DDR-001, D6, decided by Amish on 2026-09-25).
- No cameras or microphones; the device may report only slot state (free or occupied), timestamps and device health.
- No cutting or coring of the road for the prototype; the puck is bonded to the surface with two-part road-marker epoxy and is removable.
- Installation only with the road authority's permit, by a trained crew under traffic management.
- Battery powered for at least five years; no wiring in the road.
- Uses the FieldNode radio core so firmware and tools are shared across the lab.
- The sign option requires a private network server (such as TwinKit) or a city network that allows about 200 downlinks a day (decided, LDZ-DDR-002); The Things Network allows 10 per device ([TTN](https://www.thethingsnetwork.org/docs/lorawan/duty-cycle/)).
- Must survive being driven over by loaded delivery trucks, road salt, water, oil and summer road temperatures.

## Out of scope

- Payment, booking or reservation of bays (the data can feed such systems later).
- Enforcement actions or identifying vehicles; LoadZone never reads number plates.
- Passenger car parking guidance at scale (the same puck could do it, but it is not the target).
- In-ground (cored) installation, which needs road works; recorded as a later option (LDZ-DEC-001, item 7). The surface puck is not for plowed streets.

## User research and co-design

This design is for communities the author is not part of, so requirements come from the people who will use it.

- [ ] Identify a local partner organization. Decided by Amish, 2026-10-02 (LDZ-DEC-001, item 2): the first candidate type to approach, not yet agreed, is a city curb-management or transportation team that has published or piloted the Curb Data Specification, in a city without routine snow plowing
- [ ] Run co-design sessions with intended users; record who, where and what was learned
- [ ] Validate load, distance, terrain and cost assumptions in the field
- [ ] Revise requirements (REQ) from findings before freezing the design

For LoadZone the intended users are delivery drivers, a city curb or transport team and the shops on one test street. Questions for them: would drivers look at a sign, a map layer or neither; which bay lengths and slot splits are typical; and which data the city needs to act on.

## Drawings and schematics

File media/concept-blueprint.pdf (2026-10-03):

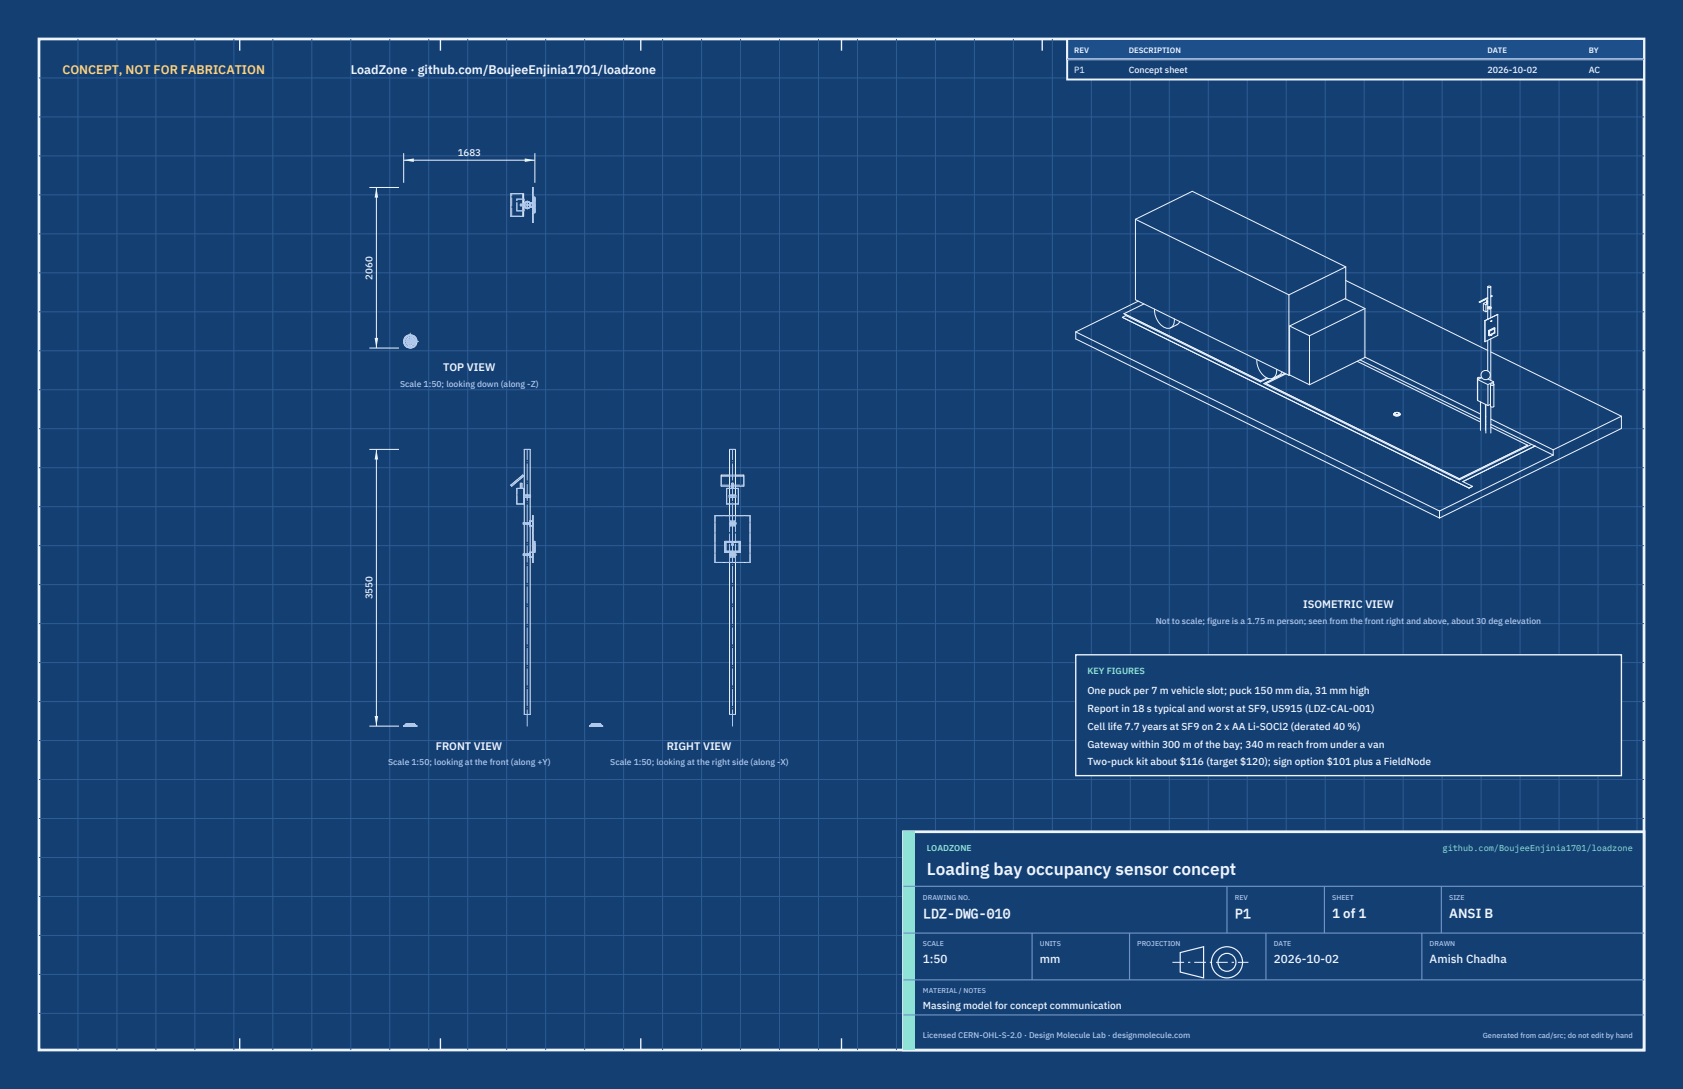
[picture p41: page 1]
CONCEPT, NOT FOR FABRICATION; LoadZone · github.com/BoujeeEnjinia1701/loadzone; FRONT VIEW; TOP VIEW; RIGHT VIEW; ISOMETRIC VIEW; REV; DESCRIPTION; DATE; Concept sheet; LOADZONE; github.com/BoujeeEnjinia1701/loadzone; DRAWING NO. LDZ-DWG-010; REV P1; SHEET 1 of 1; SIZE ANSI B; SCALE 1:50; UNITS mm; PROJECTION; DRAWN Amish Chadha; Licensed CERN-OHL-S-2.0 · Design Molecule Lab · designmolecule.com; Generated from cad/src; do not edit by hand

Scale 1:50; looking down (along -Z)

Not to scale; figure is a 1.75 m person; seen from the front right and above, about 30 deg elevation

KEY FIGURES
One puck per 7 m vehicle slot; puck 150 mm dia, 31 mm high
Report in 18 s typical and worst at SF9, US915 (LDZ-CAL-001)
Cell life 7.7 years at SF9 on 2 x AA Li-SOCl2 (derated 40 %)
Gateway within 300 m of the bay; 340 m reach from under a van
Two-puck kit about $116 (target $120); sign option $101 plus a FieldNode

Scale 1:50; looking at the front (along +Y)

Scale 1:50; looking at the right side (along -X)

Loading bay occupancy sensor concept

MATERIAL / NOTES
Massing model for concept communication

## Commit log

2026-09-25 Initial scaffold: standard open hardware layout, CERN-OHL-S v2 + MIT licenses
    Claude-Session: https://claude.ai/code/session_01XuhhSU4W6fYhgCfURbrkut
    [bom.csv]
2026-09-26 Populate to TRL 2: problem, requirements, precis, concept media, BOM and README use cases
    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
    [bom.csv]
2026-09-26 Advance to TRL 3: DDR-001, CAL-001 sizing, parametric model with STEP/STL, GA drawing, priced BOM; TRL 4 on hold
    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
    [bom.csv, loadzone-dome.step, loadzone-dome.stl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]
2026-09-26 Accept all recommendations (DDR-002), switch footer to designmolecule.com, add README write-up with new inspiration point
    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
    [bom.csv, loadzone-dome.step, loadzone-puck.step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]
2026-09-27 Product appearance model and photoreal renders
    Adds cad/src/product_model.py (appearance model for renders only, all main
    dimensions from model.py) and Blender renders in media/render-*.png,
    captioned with the project, repository and viewing direction. README leads
    with the product render; trl stays 3.
    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
2026-10-01 Image quality pass: legible exploded views, flow diagrams and drawing sheets
    Kit 1.6.1 image layout: the parts list sits in its own column, number bubbles sit on visible parts and never overlap, small parts get a leader, pictures are cropped to the subject, flow labels keep numbers with their units, and sheet captions and the revision table no longer overprint. Concept images, blueprint and general arrangement sheet regenerated; repo-specific labels moved clear of other text and lines.
2026-10-01 Kit 1.7.0: constructable design, illustrated build plan and design decisions register
    The design is now constructable: every part can be made and fits its neighbours, with each change recorded in a Design for construction decision record (made under Amish's 2026-09-30 instruction; ope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
    FlexHand also credits Dr. Geeti Chadha as a contribut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
    [bom.csv, loadzone-base-tray.step, loadzone-base-tray.stl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]
2026-10-02 Record Amish's approval of the open-decision recommendations
    Amish approved the recommendation on every open decision in the design decisions register ("i approve your recommendations for all 555 open decisions.", 2026-10-02). Each decision is moved to Decisio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
2026-10-03 Carry approved follow-ups into the design and redo photoreal renders
    Amish approved the follow-up actions from the open-decision sign-off ("APPROVED CHANGES, COMPLETE THESE", 2026-10-02), the design-for-construction change tables in ten repos, the last wave's open dec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
    [bom.csv, results.csv]

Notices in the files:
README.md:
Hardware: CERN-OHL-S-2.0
